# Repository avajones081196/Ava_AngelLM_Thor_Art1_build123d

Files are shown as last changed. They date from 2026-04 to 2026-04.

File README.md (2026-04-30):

# Ava_AngelLM_Thor_Art1_build123d

> **Reconstructing the [AngelLM Thor open-source robot arm](https://github.com/AngelLM/Thor) parts from scratch using [build123d](https://github.com/gumyr/build123d) — with automated STL comparison against the original Fusion 360 exports.**

---

## 🤖 What is This Project?

[Thor](https://github.com/AngelLM/Thor) is a fully open-source, 3D-printable robotic arm designed by AngelLM. This project takes each Thor part and **reconstructs it programmatically** using Python + build123d, driven entirely by coordinate data exported from Fusion 360.

The goal: prove that every part can be rebuilt to **near-perfect geometric accuracy** from first principles — no manual CAD, no guesswork.

---

## ✅ Parts Completed

| # | Part | Volume (mm³) | Vol Error | Sym Diff | Overlap | Bounding Box | Time | Rating |
|---|---|---|---|---|---|---|---|---|
| 1 | `Art1Top_1_Stopper` | 106.87 | 0.008% | 0.009% | 99.999% | ✅ PASS | 1 hr | 🟢 EXCELLENT |
| 2 | `Art1Top_Splitted_A` | 107,906.06 | 0.023% | 0.030% | 99.973% | ✅ PASS | 3.5 hrs | 🟢 EXCELLENT |
| 3 | `Art1Top_Splitted_B` | 45,416.29 | 0.030% | 0.065% | 99.952% | ✅ PASS | 40 min | 🟢 EXCELLENT |
| 4 | `Art2BodyA_Splitted_A` | 102,778.90 | 0.199% | 0.579% | 99.613% | ✅ PASS | 17 hrs | 🟢 EXCELLENT |
| 5 | `Art2BodyA_Splitted_B` | 88,495.39 | 0.058% | 0.283% | 99.887% | ✅ PASS | 10 hrs | 🟢 EXCELLENT |

> **All 5 completed parts: 🟢 EXCELLENT across every metric.**

⏱ **Total time: 32 hrs 10 min**

---

## 📊 Art2BodyA_Splitted_B — Detailed Results

### What the part looks like

A teardrop-shaped body with the hole positioned at the **top** of the teardrop (not at the bulge like Splitted_A) — essentially the geometric counterpart to Splitted_A:

- **Teardrop outer body** (S1): 4 outer arcs (Arc 1 r=75 bottom, Arc 2/Arc 4 r=65 tangents, Arc 3 r=65 top) with a Ø98 mm through-hole at (0, 160). Extruded -32 mm in Z.
- **U-channel pocket** (S2 / G5): irregular crescent + tongue region between Arc 1 of S2 (r=60 inner) and the body's outer boundary, cut 28 mm deep from Z=33 → Z=5, leaving a 5 mm floor.
- **Patterned cluster × 3** (S3, S4 / G6–G10): each instance contains a slot tab (G7), a rectangle-with-hole tab (G8), and a pentagon-shaped through-window cut (G9). Pattern axis: vertical at (0, 160) — centre of the S1 hole.
- **Bounding-box-with-circle feature** (S5 / G11–G13): rect + arc bounding box plus an inner circle, extruded -12.1 mm; circle then cut -12.0 mm leaving a 0.1 mm floor under the hole.
- **Symmetric line-loop cut** (S6 / G14–G15): closed line profile cut ±1.5 mm in Z.
- **Three diameter-bucketed hole sets** (S7 / G16–G19): Ø8.4 / Ø5.9 / Ø3.4 circles cut to depths 2.1 / 3.9 / 8 mm respectively from Z=-1.
- **YZ-plane through-bore** (S8 / G20–G21): single circle cut symmetrically ±50 mm along X.
- **Two YZ-plane prisms** (S9 / G22–G24): two enclosed loops auto-grouped from line endpoints, extrude-joined 30 mm and 26 mm in -X.
- **XY-plane line cutout** (S10 / G25–G26): closed line profile cut 3.5 mm in -Z.
- **YZ-plane mirror** (G27): everything from G22–G26 mirrored across the global YZ plane (S9 prisms re-built at +X with positive extrudes; S10 cutout with X-coords negated).
- **Bottom-face fillets** (G28): 4.99 mm fillet on the three r=65 outer arcs at z=0 (skip Arc 1 r=75). The 4.99 vs 5.0 sidesteps an OCC kernel edge case where exactly r=5 fails on this geometry — 0.01 mm difference is below STL tolerance.

### Guidelines breakdown (G1–G10 + G28; G11–G27 are part of the body construction within the BuildPart context)

| Guideline | Description | CSV |
|---|---|-----|
| G1 | Read S1; circle + 4 arcs at Z=32 → teardrop outline + Ø98 hole | S1 |
| G2 | Extrude outer-arcs-minus-hole region -32 mm in Z | S1 |
| G3 | (Logic stage) export STL/STEP at LAST stage | — |
| G4 | Read S2; identify 3 enclosed sections (hole, U-channel, rim crescent) | S2 |
| G5 | Extrude-cut Sections 2 ∪ 3 by -28 mm; sketch at Z=33 (1 mm overshoot) | S2 |
| G6 | Read S3 + S4; parse 3 sections of S3 + pentagon of S4 | S3, S4 |
| G7 | Extrude-join slot section (Section 3) +8.1 mm in +Z; sketch at Z=4.9 (0.1 mm overshoot into floor) | S3 |
| G8 | Extrude-join rectangle-minus-circle (Section 2) +6 mm at offset Z=7 | S3 |
| G9 | Extrude-cut pentagon (S4) symmetrically ±1.5 mm at Z=10 | S4 |
| G10 | Circular pattern of (G6→G9) × 3 at 0°, 120°, 240° around (0, 160) Z-axis | — |
| G11 | Read S5; bounding-box (lines + arc) + inner circle | S5 |
| G12 | Extrude-join BOTH S5 sections -12.1 mm in -Z | S5 |
| G13 | Extrude-cut S5 inner circle -12.0 mm in -Z (leaves 0.1 mm floor) | S5 |
| G14 | Read S6; closed line loop | S6 |
| G15 | Extrude-cut S6 profile symmetrically ±1.5 mm in Z | S6 |
| G16 | Read S7; bucket circles by Ø8.4 / Ø5.9 / Ø3.4 | S7 |
| G17 | Extrude-cut Ø8.4 circles +2.1 mm in +Z (sketch at Z=-1) | S7 |
| G18 | Extrude-cut Ø5.9 circles +3.9 mm in +Z | S7 |
| G19 | Extrude-cut Ø3.4 circles +8 mm in +Z | S7 |
| G20 | Read S8; circle on YZ plane | S8 |
| G21 | Extrude-cut S8 circle symmetrically ±50 mm in X (through-bore) | S8 |
| G22 | Read S9; auto-group lines into 2 closed loops on YZ plane at X=-9 | S9 |
| G23 | Extrude-join Loop A (Y ∈ [103.7, 108.7]) -30 mm in -X | S9 |
| G24 | Extrude-join Loop B -26 mm in -X | S9 |
| G25 | Read S10; closed line loop on XY plane at Z=8.5 | S10 |
| G26 | Extrude-cut S10 profile -3.5 mm in -Z | S10 |
| G27 | Mirror G22–G26 across global YZ plane (S9 re-built at +X with +X extrudes; S10 X-coords negated) | — |
| G28 | Fillet 3 bottom-face outer arcs (r≈65) at z=0 with r=4.99 mm | — |

### Comparison scorecard

```
███████████████████████████████████████████████████████████
  STL COMPARISON: Build123d  vs  Fusion 360 Original
███████████████████████████████████████████████████████████

  Build123d volume    : 88,495.39 mm³
  Fusion 360 volume   : 88,444.34 mm³
  Absolute difference :     +51.05 mm³  (build123d larger)
  % error             :     0.058%      🟢 EXCELLENT

  Symmetric diff      :    250.53 mm³
  Sym diff %          :     0.283%      🟢 EXCELLENT
  Overlap coverage    :    99.887%      🟢 EXCELLENT

  Bounding box        : ✅ ALL 6 AXES PASS  (max deviation 0.010 mm)

  ─────────────────────────────────────────────────────────
  SUMMARY SCORECARD
  ─────────────────────────────────────────────────────────
  Volume % error          0.058%   🟢 EXCELLENT
  Symmetric diff % error  0.283%   🟢 EXCELLENT
  Overlap coverage       99.89%    ✅
  Bounding box             PASS    ✅
```

### Lessons learned (the 10-hour debug arc)

This part hammered home several Boolean-kernel lessons that build on (and refine) the rules from Splitted_A:

1. **Z-overshoot beats radial offset, every time.** When a cutter or join feature shares a sketch boundary with the host body, the wrong fix is to nudge the radius by 0.01 mm — that creates a sub-tolerance sliver wall that survives `.clean()` but breaks STL tessellation. The right fix is to **extend the cutter perpendicular to the shared face by 1 mm** (e.g. sketch the cutter at Z=33 when the body top is Z=32). The overshoot lives in empty space; the 1 mm margin is 2000× the STL tolerance, well clear of any numerical edge case. Used this for G5 (cut), G7/G13 (join into floor), and the G15 symmetric cut.
2. **For multiple enclosed regions sharing internal dividers, build the union.** S2 had three sections with three "T-junction" divider edges. Drawing each section separately would have made build123d struggle with the shared edges. Instead I traced the **outer perimeter of (Section 2 ∪ Section 3)** as one closed loop — the dividers become interior to the union and vanish. Verified via Euler's formula (V−E+F=2 → exactly 2 bounded faces in the planar graph, confirming "three enclosed sections" reading).
3. **Fillet is the one place where 4.99 vs 5.00 actually matters.** OCC's `fillet()` rejected exactly r=5.0 on the three r=65 bottom arcs (binary search converged: r=4.999... works, r=5.000 fails). Unlike sketch-coincident cases where 0.01 mm offsets create slivers, **fillet is a face-blend operation** — the resulting tangent surface is geometrically clean regardless of the 0.01 mm difference. Visually and dimensionally indistinguishable from r=5.0; OCC just numerically prefers it.
4. **Volume diagnostic libraries don't all agree.** Initial compare report showed a phantom 0.55% volume error because `numpy-stl`'s `get_mass_properties()` integrates signed tetrahedra straight from raw STL triangles — and tessellation of curved fillet surfaces sometimes emits a handful of inverted triangles. trimesh normalizes triangle winding on load and gave the correct value (matching build123d's BREP volume to 4 decimal places). **Use trimesh consistently for all mesh metrics**, not numpy-stl. After fixing the compare script, the real volume error dropped from 0.55% to 0.058% — 10× better.

---

## 📊 Art2BodyA_Splitted_A — Detailed Results

### What the part looks like

The most complex part yet — a stepped teardrop body with a **60-tooth helical gear ring**:

- **Stepped teardrop base**: sections 1+2 (circle + crescent) span Z=0..32; section 3 (bulge) sits on top from Z=5..32
- **Multi-depth pockets** on top face (sections cut to depths -29, -19, -22 mm)
- **4 small bores** (Ø3.4 mm) in bulge floor; central counterbore (Ø10 mm) and through-bore (Ø16.4 mm) clusters
- **Two hexagonal recesses** at Z=11 (circumradius ≈ 3.35 mm)
- **Truncated cone boss** (loft from r=18 @ Z=5 to r=12 @ Z=11), extruded to base
- **Two pentagonal extrusions** on the YZ side face at Y=83 (joined by 6 mm in -Y)
- **60-tooth helical gear ring**: each tooth swept along Z=13→Z=3 with 5.97° twist, patterned around global Z-axis (radial range r=57.5 → 62.92 mm)

### Guidelines breakdown (31 guidelines, G1–G31)

| Guideline | Description | CSV |
|---|---|-----|
| G1 | Read S1; sketch circle + 4 arcs at Z=32 → 3 enclosed sections | S1 |
| G2 + G4 | **Stepped teardrop via cut-first**: full silhouette extrude Z=32→0, then Boolean cut for bulge below Z=5 | S1 |
| G3 | (Logic stage) Base complete | — |
| G5 | Fillet bottom-face arcs r=5 mm (skip Arc 2 r=75) | — |
| G6–G9 | S2 cuts on top face (circle / crescent / bulge: -29 / -19 / -22 mm) | S2 |
| G10–G11 | 4 small bores in bulge floor (-6 mm) | S3 |
| G12–G13 | S4 single circle from bottom face (+1.1 mm) | S4 |
| G14–G16 | S5 loft + extrude-join (truncated cone) | S5 |
| G17–G18 | S6 holes & slot cluster on bottom face | S6 |
| G19–G21 | S7 three sections, two depths (4 mm and 9 mm) | S7 |
| G22–G23 | S8 two hexagon recesses at Z=11 | S8 |
| G24–G25 | S9 two pentagon extrude-joins on YZ plane | S9 |
| G26–G27 | S10 ring extrude-join (Z=13 → Z=2.7) | S10 |
| G28–G29 | S11 tooth profile + S12 sweep path | S11, S12 |
| G30 | Helical tooth via 21-slice rotated loft (twist +5.97°) | — |
| G31 | Circular pattern × 60 around global Z-axis | — |

### Comparison scorecard

```
███████████████████████████████████████████████████████████
  STL COMPARISON: Build123d  vs  Fusion 360 Original
███████████████████████████████████████████████████████████

  Build123d volume    : 102,778.90 mm³
  Fusion 360 volume   : 102,979.85 mm³
  Absolute difference :    -204.77 mm³
  % error             :     0.199%      🟢 EXCELLENT

  Symmetric diff      :     596.42 mm³
  Sym diff %          :     0.579%      🟢 EXCELLENT
  Overlap coverage    :    99.613%      🟢 EXCELLENT

  Bounding box        : ✅ ALL 6 AXES PASS  (max deviation 0.010 mm)

  ─────────────────────────────────────────────────────────
  SUMMARY SCORECARD
  ─────────────────────────────────────────────────────────
  Volume % error          0.199%   🟢 EXCELLENT
  Symmetric diff % error  0.579%   🟢 EXCELLENT
  Overlap coverage       99.61%    🟢 EXCELLENT
  Bounding box             PASS    ✅
```

### Lessons learned (the 17-hour debug arc)

This part exposed several Boolean-kernel pitfalls that the simpler Art1 parts didn't hit. The key fixes — written up as universal rules in [`build123d_short_prompts.md`](./build123d_short_prompts.md) — are:

1. **Never share a sketch curve between two extrudes that get fused.** G2 + G4 originally extruded sections 1+2 and all-3-sections separately, both containing Arc 2 in their sketches. The fuse left Arc 2 as an internal seam → 14 open edges. **Fix**: build the full outer silhouette in one extrude, then Boolean-cut the bulge below Z=5.
2. **Avoid coincident faces between cutter and host.** First cut attempt produced 1483 open edges because the cutter's side walls (Arcs 3, 4, 1) sat exactly coincident with the host's outer walls. **Fix**: replace those arcs with a generous bounding rectangle that lies entirely outside the host. Boolean only acts where they overlap, so the rectangle's overhang is geometrically free.
3. **Z-inset for swept teeth.** Tooth path of exact Z=13→Z=3 produced 9 open edges where tooth end-faces coincided with the ring's top/bottom faces. **Fix**: shrink path 0.05 mm at each end (Z=12.95 → Z=3.05). Each tooth ends 0.05 mm *inside* the ring at top and bottom — invisible because the ring's flat top/bottom faces project over those gaps, and the Boolean fuse is now isolated from coincident-face conflicts.
4. **Three-gate STL validator before export.** trimesh's `is_watertight=True` does NOT guarantee Fusion will accept the STL — Fusion also checks face-orientation consistency and positive signed volume. **Fix**: always run `trimesh.repair.fix_winding()` + `fix_normals()` before export, then gate on three checks: watertight + positive volume + volume matches BREP within 1%.

---

## 📊 Art1Top_Splitted_B — Detailed Results

### What the part looks like

A stepped annular ring with three concentric circles defining two regions:

- **Inner ring** (r25→r35): extends both upward (+7 mm) and downward (-6 mm) from the sketch plane
- **Outer flange** (r25→r47): extends upward (+7 mm) only
- **6 bolt holes** (r≈1.7 mm) on a 30 mm bolt circle, evenly spaced

### Guidelines breakdown (6 guidelines, G1–G6)

| Guideline | Description | CSV |
|---|---|-----|
| G1 | Read 3 concentric circles (inner r=25, middle r=35, outer r=47) | S1 |
| G2 | Extrude inner-to-middle -6 mm (-Z) and +7 mm (+Z); inner-to-outer +7 mm (+Z) join | S1 |
| G3 | (Logic stage) Ring complete | — |
| G4 | Read bolt hole circle (r≈1.7 mm at radius 30 mm) | S2 |
| G5 | Extrude-cut hole 15 mm through-all | S2 |
| G6 | Circular pattern × 6 around global Z axis | — |

### Comparison scorecard

```
███████████████████████████████████████████████████████████
  STL COMPARISON: Build123d  vs  Fusion 360 Original
███████████████████████████████████████████████████████████

  Build123d volume    : 45,416.29 mm³
  Fusion 360 volume   : 45,429.81 mm³
  Absolute difference :    −13.52 mm³
  % error             :     0.030%      🟢 EXCELLENT

  Symmetric diff      :     29.74 mm³
  Sym diff %          :     0.065%      🟢 EXCELLENT
  Overlap coverage    :    99.952%      🟢 EXCELLENT

  Bounding box        : ✅ ALL 6 AXES PASS  (max deviation 0.015 mm)

  ─────────────────────────────────────────────────────────
  SUMMARY SCORECARD
  ─────────────────────────────────────────────────────────
  Volume % error          0.030%   🟢 EXCELLENT
  Symmetric diff % error  0.065%   🟢 EXCELLENT
  Overlap coverage       99.95%    🟢 EXCELLENT
  Bounding box             PASS    ✅
```

---

## 📊 Art1Top_Splitted_A — Detailed Results

### What the part looks like

A large annular disc (inner radius 25 mm, outer radius 75 mm) with multiple features:

- **6 countersink holes** on a 30 mm bolt circle (counterbore + through-bore)
- **4 rectangular bosses** with side holes, pentagon slots, and wedge extrusions (mirrored in 4 quadrants)
- **Tilted hex + circle cuts** on 45° angled faces
- **Curved cutout profiles** at wedge bases
- **Bottom-face pocket** (circle cut from Z=0)

### Guidelines breakdown (20 guidelines, G1–G20)

| Guideline | Description | CSV |
|---|---|-----|
| G1–G3 | Annular ring (inner/outer circles, extrude −5 mm) | S1 |
| G4–G6 | Countersink holes × 6 (counterbore +3, through-bore −2, circular pattern) | S2 |
| G7–G8 | Rectangular boss (10×23 mm, extrude +15 mm) | S3 |
| G9–G10 | Side hole through rectangular boss | S4 |
| G11–G12_1 | Wedge profile extrusions (triangle +13, polygon +5) | S5 |
| G12_2–G12_3 | Curved cutout at wedge base (+30 mm cut) | S9 |
| G13–G14 | Hexagon + circle cut on 45° tilted plane | S6 |
| G15–G16 | Pentagon slot cut (±1.5 mm symmetric) | S7 |
| G17 | Mirror G7–G16 across YZ plane (X → −X) | — |
| G18 | Mirror G7–G17 across XZ plane (Y → −Y) | — |
| G19–G20 | Bottom-face circle pocket (r=5 mm, 2 mm deep) | S8 |

### Comparison scorecard

```
  Build123d volume    : 107,906.06 mm³
  Fusion 360 volume   : 107,931.29 mm³
  % error             :     0.023%      🟢 EXCELLENT

  Symmetric diff %    :     0.030%      🟢 EXCELLENT
  Overlap coverage    :    99.973%      🟢 EXCELLENT
  Bounding box        : ✅ ALL 6 AXES PASS
```

---

## 📊 Art1Top_1_Stopper — Detailed Results

### What the part looks like

A circular disc (radius ≈ 4.4 mm) with a raised central strip — two parallel chord lines inside the circle divide it into three regions:

```
        ╭─────────────────╮
        │   Region B (arc)│   ← flat
        ├─────────────────┤   ← chord at Y = +1.5
        │   Region A      │   ← raised +1.0 mm (the "stopper" ridge)
        ├─────────────────┤   ← chord at Y = -1.5
        │   Region C (arc)│   ← flat
        ╰─────────────────╯
```

### Comparison scorecard

```
  Build123d volume    : 106.87 mm³
  Fusion 360 volume   : 106.86 mm³
  % error             :   0.008%       🟢 EXCELLENT

  Symmetric diff %    :   0.009%       🟢 EXCELLENT
  Overlap coverage    :  99.999%       🟢 EXCELLENT
  Bounding box        : ✅ ALL 6 AXES PASS
```

---

## 🗂️ Project Structure

Each part lives in its own folder under `20260422_assign/`:

```
20260422_assign/
├── Art1Top_1_Stopper/
│   ├── csv_data_Art1Top_1_Stopper/
│   ├── csv_merged/
│   ├── 0_preprocess_csvs.py
│   ├── Art1Top_1_Stopper_build123d.py
│   ├── Art1Top_1_Stopper_compare_stl_files.py
│   ├── Art1Top_1_Stopper_G_1_3.stl
│   ├── Art1Top_1_Stopper_G_1_3.step
│   └── Art1Top_1_Stopper_original.stl
│
├── Art1Top_Splitted_A/
│   ├── csv_data_Art1Top_Splitted_A/
│   ├── csv_merged/                        ← S1–S9 cleaned CSVs
│   ├── 0_preprocess_csvs.py
│   ├── Art1Top_Splitted_A_build123d.py    ← 20 guidelines (G1–G20)
│   ├── Art1Top_Splitted_A_compare_stl_files.py
│   ├── Art1Top_Splitted_A_G_1_20.stl
│   ├── Art1Top_Splitted_A_G_1_20.step
│   └── Art1Top_Splitted_A_original.stl
│
├── Art1Top_Splitted_B/
│   ├── csv_data_Art1Top_Splitted_B/
│   ├── csv_merged/                        ← S1–S2 cleaned CSVs
│   ├── 0_preprocess_csvs.py
│   ├── Art1Top_Splitted_B_build123d.py    ← 6 guidelines (G1–G6)
│   ├── Art1Top_Splitted_B_compare_stl_files.py
│   ├── Art1Top_Splitted_B_G_1_6.stl
│   ├── Art1Top_Splitted_B_G_1_6.step
│   └── Art1Top_Splitted_B_original.stl
│
├── Art2BodyA_Splitted_A/
│   ├── csv_data_Art2BodyA_Splitted_A/
│   ├── csv_merged/                        ← S1–S12 cleaned CSVs
│   ├── 0_preprocess_csvs.py
│   ├── Art2BodyA_Splitted_A_build123d.py  ← 31 guidelines (G1–G31)
│   ├── Art2BodyA_Splitted_A_compare_stl_files.py
│   ├── Art2BodyA_Splitted_A_G_1_31.stl
│   ├── Art2BodyA_Splitted_A_G_1_31.step
│   └── Art2BodyA_Splitted_A_original.stl
│
└── Art2BodyA_Splitted_B/
    ├── csv_data_Art2BodyA_Splitted_B/
    ├── csv_merged/                        ← S1–S10 cleaned CSVs
    ├── 0_preprocess_csvs.py
    ├── Art2BodyA_Splitted_B_build123d.py  ← G1–G10 + G28 (G11–G27 in body construction)
    ├── Art2BodyA_Splitted_B_compare_stl_files.py
    ├── Art2BodyA_Splitted_B_G_1_28.stl
    ├── Art2BodyA_Splitted_B_G_1_28.step
    └── Art2BodyA_Splitted_B_original.stl
```

---

## 🔧 How It Works

### The Pipeline (3 scripts per part)

```
Raw Fusion CSVs
      ↓
[0_preprocess_csvs.py]     → cleans duplicates, merges split files → csv_merged/
      ↓
[PartName_build123d.py]    → reads CSVs, builds 3D geometry, exports STL + STEP
      ↓
[PartName_compare_stl_files.py]  → compares built STL vs Fusion original
```

---

### Script 1 — `0_preprocess_csvs.py`

Reads raw Fusion 360 coordinate CSVs and produces clean, deduplicated versions:

- Handles split files (e.g. `S25_1.csv + S25_2.csv → S25.csv`)
- Removes geometry-aware duplicates:
  - Lines: `A→B == B→A` (direction-invariant)
  - Triangles: `A,B,C == B,C,A` (rotation-invariant)
  - Points: exact match
- Renumbers `Steps` column sequentially
- **Incremental** — skips shapes already in `csv_merged/` (safe to re-run)

---

### Script 2 — `PartName_build123d.py`

Rebuilds the part using [build123d](https://github.com/gumyr/build123d). Each script follows a numbered guideline system:

| Guideline | Always means |
|---|---|
| **G1** | Read CSV(s), extract geometry (circles, lines, polygons) |
| **G2–Gn** | Perform extrusions, cuts, sweeps, patterns, mirrors etc. |
| **Last G** | Always last — `clean()` → watertight check → export STL + STEP → write summary |

**File naming convention:**
```
PartName_G_1_N.stl          ← STL output  (N = last guideline number)
PartName_G_1_N.step         ← STEP output
PartName_summary_G_1_N.txt  ← Build log
```

**Pre-export validator (since Art2BodyA_Splitted_A)** — replaces the simple watertight check, gates on three conditions:

```python
trimesh.repair.fix_winding(mesh)   # consistent CCW winding
trimesh.repair.fix_normals(mesh)   # outward-pointing normals

wt      = mesh.is_watertight
pos_vol = mesh.volume > 0
vol_ok  = abs(mesh.volume - brep_vol) / abs(brep_vol) < 0.01

if wt and pos_vol and vol_ok:
    mesh.export(STL_PATH)          # ship validated mesh
```

This eliminates the *"mesh not oriented / not positive volume"* error Fusion would intermittently throw on import — Fusion checks face orientation in addition to manifoldness, and `is_watertight=True` alone doesn't guarantee that.

---

### Script 3 — `PartName_compare_stl_files.py`

Compares the built STL against the original Fusion 360 STL across four metrics:

| Metric | What it measures |
|---|---|
| **Volume % error** | How close the total volume is |
| **Symmetric difference** | Spatial overlap quality — how well the shapes align in 3D space |
| **Overlap coverage** | What % of the original is covered by the reconstruction |
| **Bounding box** | Whether all 6 axis extents match within ±0.1 mm |

Ratings: 🟢 EXCELLENT / 🟡 GOOD / 🟠 ACCEPTABLE / 🔴 POOR

> **⚠ Important — use `trimesh` consistently for volume.** Earlier versions of the compare script used `numpy-stl`'s `get_mass_properties()` for the headline volume reading and `trimesh` for the symmetric-difference section, which gave **two different volumes for the same file** on meshes with many curved fillet faces (Splitted_B initially showed a phantom 0.55% error this way). Cause: numpy-stl integrates signed tetrahedra straight from raw STL triangles, while trimesh normalizes triangle winding on load. Fix: replace the `from stl import mesh` reading with `trimesh.load(file).volume` everywhere — apples-to-apples comparison.

---

## 🛠️ Environment Setup

### Requirements

- Python 3.11
- macOS (tested on MacBook Air, Apple Silicon)
- VS Code + [OCP CAD Viewer extension](https://github.com/bernhard-42/vscode-ocp-cad-viewer)

### Create the master environment

```bash
python3.11 -m venv ~/Documents/ava_build123d/build123d_master_env
source ~/Documents/ava_build123d/build123d_master_env/bin/activate
pip install --upgrade pip
pip install build123d==0.7.0 ocp_vscode==3.3.4 numpy-stl trimesh manifold3d rtree networkx
```

> `networkx` is optional — used by trimesh for boundary-loop stitching during mesh repair. Recommended.

### Add a handy shell alias (optional but recommended)

```bash
echo 'alias buildenv="source ~/Documents/ava_build123d/build123d_master_env/bin/activate"' >> ~/.zshrc
source ~/.zshrc
```

Now you can just type `buildenv` to activate.

---

## 🚀 Running a Part (Master Startup Checklist)

### 🔧 One-Time Per Project Folder

1. **Open project folder** in VS Code: `File` → `Open Folder`
2. **Lock the interpreter:**
   ```bash
   mkdir -p .vscode && cat > .vscode/settings.json << 'EOF'
   {
       "python.defaultInterpreterPath": "/Users/avajones/Documents/ava_build123d/build123d_master_env/bin/python"
   }
   EOF
   ```

### ▶️ Every Session

3. **Open OCP viewer:** `Cmd+Shift+P` → `OCP CAD Viewer: Open Viewer`
   - If interpreter prompt appears → click `yes` → pick `build123d_master_env`
4. **Check port:** read bottom-right corner `OCP: XXXX` — match in script's `set_port(XXXX)`
5. **Tab 2 — run scripts:**
   ```bash
   buildenv
   cd ~/Documents/ava_build123d/20260422_assign/PartName
   python 0_preprocess_csvs.py
   python PartName_build123d.py
   python PartName_compare_stl_files.py
   ```

> **Port note:** The OCP viewer port varies per session. Always check `OCP: XXXX` in the bottom-right corner of VS Code and match `set_port()` accordingly.

---

## 🐛 Known Gotchas

| Issue | Cause | Fix |
|---|---|-----|
| `Connection refused Errno 61` | OCP server not running | Open OCP viewer panel before running script |
| Geometry not showing | Script port ≠ viewer port | Match `set_port()` to bottom-right `OCP: XXXX` |
| Script runs old version | Unsaved file (● dot on tab) | `Cmd+S` — confirm dot disappears |
| `No module named ocp_vscode` | VS Code using wrong Python | Run `.vscode/settings.json` fix once per folder |
| `Location()` on `Plane.YZ` misplaced | `Location` uses **global** coords, not local | Use `Location((0, Y, Z))` not `Location((Y, Z, 0))` |
| Thin surface artifact on cuts | Sketch plane sits exactly on body face | Use `both=True` to cut in both directions |
| `Location` context manager error | `with Location(...)` not supported | Use `Plane.move(Location(...))` instead |
| `open_edges = 14` after fuse | Two extrudes share a sketch curve → internal seam | Single outer-silhouette extrude + Boolean cut |
| `open_edges` = 1000+ after cut | Cutter side walls coincident with host walls | Replace cutter outline with bounding rectangle outside host |
| Fusion: *"mesh not oriented"* on import | trimesh `is_watertight` doesn't check face orientation | Always run `fix_winding` + `fix_normals` before export |
| Script hangs mid-run | Intermediate `show()` blocking | Comment out all but final `show()` |
| Sliver wall after sketch-coincident cut | Tried 0.01 mm radial offset to avoid coincidence | Use Z-overshoot instead — extend cutter ≥1 mm in extrude direction |
| `fillet(r=5.0)` rejected on tangent arcs | OCC kernel numerical edge case at exact radius | Use 4.99 — face-blend op, 0.01 mm difference is below STL tolerance |
| Compare script reports 0.5% phantom volume error | numpy-stl + trimesh disagree on filleted meshes | Use `trimesh.load(f).volume` consistently in compare script |

---

## 📦 Dependencies

```
build123d==0.7.0
ocp_vscode==3.3.4
numpy-stl
trimesh
manifold3d
rtree
networkx          # optional — trimesh boundary-loop stitching
```

---

## 🗺️ Roadmap

- [x] `Art1Top_1_Stopper` — 🟢 EXCELLENT (0.008% vol error) — 1 hr
- [x] `Art1Top_Splitted_A` — 🟢 EXCELLENT (0.023% vol error) — 3.5 hrs
- [x] `Art1Top_Splitted_B` — 🟢 EXCELLENT (0.030% vol error) — 40 min
- [x] `Art2BodyA_Splitted_A` — 🟢 EXCELLENT (0.199% vol error) — 17 hrs
- [x] `Art2BodyA_Splitted_B` — 🟢 EXCELLENT (0.058% vol error) — 10 hrs

---

## 📄 License

This reconstruction project is open source. The original Thor design files belong to [AngelLM](https://github.com/AngelLM/Thor) under their respective license.

---

## 🙏 Credits

- **[AngelLM](https://github.com/AngelLM)** — original Thor robot arm design
- **[build123d](https://github.com/gumyr/build123d)** — the Python CAD library powering all reconstructions
- **[OCP CAD Viewer](https://github.com/bernhard-42/vscode-ocp-cad-viewer)** — VS Code 3D preview
- **[trimesh](https://trimesh.org/)** + **[manifold3d](https://github.com/elalish/manifold)** — STL comparison engine

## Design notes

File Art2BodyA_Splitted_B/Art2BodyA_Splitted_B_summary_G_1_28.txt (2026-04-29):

============================================================
Summary  :  Art2BodyA_Splitted_B_summary_G_1_28
Guidelines covered: G1 to G28
============================================================

-- G1 : Profile (S1, Z=32) --
  Inner Circle (hole) : centre=(0.000, 160.000)  r=49.000
  Arc 1 (bottom)      : centre=(0.000, -0.001)  r=75.001
  Arc 2 (right tang.) : centre=(102.470, 80.000)  r=65.000
  Arc 3 (top conn.)   : centre=(0.000, 160.000)  r=65.000
  Arc 4 (left tang.)  : centre=(-102.470, 80.000)  r=65.000
  Sketch plane Z = 32.0

-- G2 : Extrude region (outer arcs minus circle hole) --
  Depth: -32.0 mm in -Z  (Z=32.0 -> Z=0)

-- G4 : Profile (S2, Z=33) — three enclosed sections --
  Section 1 (HOLE, NOT cut): circle r=49.000 at (0.000, 160.000)  dia=98.000
  Section 2 (upper U-channel)
  Section 3 (rim crescent)

-- G5 : Extrude-cut Sections 2 ∪ 3 (NOT Section 1) --
  Sketch Z = 33.0  (1 mm above body top Z=32 — Z-overshoot)
  Cut depth: 28.0 mm in -Z   (Z=33.0 → Z=5.0)
  Result: 5 mm floor at Z=0..5; pocket reaches body sidewalls

-- G6 : Profile (S3, Z=4.9) — three enclosed sections --
  Section 1 : circle r=1.700 at (0.000, 205.000)
  Section 2 : rectangle (-5,201)→(5,209) MINUS Section-1 circle
  Section 3 : slot lines+arc (top arc r=64.863 c=(-0.000, 155.621))
  Sketch plane Z = 4.9  (0.1 mm BELOW floor top Z=5 — Z-overshoot)

-- G7 : Extrude-join Section 3 (slot) --
  Depth: +8.1 mm in +Z  (Z=4.9 → Z=13.0)

-- G8 : Extrude-join Section 2 (rect - circle) --
  Offset: +2.1 mm above sketch plane → start Z=7.0
  Depth:  +6.0 mm in +Z  (Z=7.0 → Z=13.0)
  Circle hole carries through Section-2 tab (Z=7.0..13.0)

-- G9 : Profile (S4, Z=10) + symmetric extrude-cut --
  S4 profile: pentagon-like outline (7 lines, closed)
  Sketch plane Z = 10.0
  Cut: ±1.5 mm symmetric in Z  (Z=8.5 → Z=11.5, total 3.0 mm)
  Implementation: TWO subtract extrudes from sketch (+1.5 and -1.5)

-- G10 : Circular pattern of (G6 → G9) --
  Pattern axis: vertical at (0.0, 160.0) (centre of S1 circle)
  Quantity: 3 instances at 0.0°, 120.0°, 240.0°
  G7+G8 join, G9 cut applied at each rotated position

-- G11 : Profile (S5, Z=25.0) — bounding box (lines+arc) + inner circle --
  Inner circle: centre=(0.000, 215.000)  r=1.700
  Bounding box: rectangle x=[-5, 5], y=[210, 219.791] + small step to y=220.391 + top arc

-- G12 : Extrude-join BOTH S5 sections (box + circle) --
  Depth: -12.1 mm in -Z  (Z=25.0 → Z=12.9)

-- G13 : Extrude-cut S5 inner circle --
  Depth: -12.0 mm in -Z  (Z=25.0 → Z=13.0)
  Leaves 0.1 mm of material under the hole at the bottom of the G12 prism

-- G14 : Profile (S6, Z=20.5) — closed loop of lines --
  S6 profile: 7 lines forming a single closed loop

-- G15 : Extrude-cut S6 profile symmetrically --
  Cut: ±1.5 mm symmetric in Z  (Z=19.0 → Z=22.0, total 3.0 mm)
  Implementation: TWO subtract extrudes from sketch (+1.5 and -1.5)

-- G16 : Profile (S7, Z=-1.0) — circles bucketed by diameter --
  Circles dia ≈ 8.4: 2 found
  Circles dia ≈ 5.9: 4 found
  Circles dia ≈ 3.4: 4 found

-- G17 : Extrude-cut dia ≈ 8.4 circles --
  Depth: +2.1 mm in +Z  (Z=-1.0 → Z=1.1)
  Produces 1.1 mm-deep counterbore-style holes through floor at Z=0

-- G18 : Extrude-cut dia ≈ 5.9 circles --
  Depth: +3.9 mm in +Z  (Z=-1.0 → Z=2.9)

-- G19 : Extrude-cut dia ≈ 3.4 circles --
  Depth: +8.0 mm in +Z  (Z=-1.0 → Z=7.0)

-- G20 : Profile (S8, YZ-plane at X=0.0) — circle --
  Circle: centre_Y=99.850, centre_Z=8.000  r=1.700

-- G21 : Extrude-cut S8 circle symmetrically along X --
  Cut: ±50 mm symmetric in X  (through-bore along X)
  Implementation: TWO subtract extrudes from YZ sketch (+50 and -50)

-- G22 : Profile (S9, YZ-plane at X=-9.0) — TWO closed loops --
  Auto-grouped into 2 loops by walking endpoints
  Loop A (Y range 103.7→108.7): 6 lines
  Loop B (other):                6 lines

-- G23 : Extrude-join Loop A by 30 mm in -X --
  Sketch at X=-9.0 → solid extends toward X=-39.0

-- G24 : Extrude-join Loop B by 26 mm in -X --
  Sketch at X=-9.0 → solid extends toward X=-35.0

-- G25 : Profile (S10, Z=8.5) — single enclosed region --
  S10 profile: 7 lines forming a single closed loop

-- G26 : Extrude-cut S10 profile by 3.5 mm in -Z --
  Cut: Z=8.5 → Z=5.0

-- G27 : Mirror G22-G26 across the global YZ plane --
  S9 features re-built at X=9.0 (mirror of -9.0)
    Loop A extruded +30 mm in +X
    Loop B extruded +26 mm in +X
  S10 feature: every X coordinate negated, then cut -3.5 mm in -Z

-- G28 : Fillet 3 bottom-face outer arcs (r≈65) at z=0 --
  Selection: bottom face via faces().sort_by(Axis.Z)[0], filter edges by radius ≈65
  Fillet radius applied: 4.99 (literal 5.0 fails OCC kernel; 0.01 mm difference
    is below STL tolerance, visually identical)
  Skipped Arc 1 (r=75 bottom of teardrop)

-- G3 : Export --
  STL  : Art2BodyA_Splitted_B_G_1_28.stl
  STEP : Art2BodyA_Splitted_B_G_1_28.step

Watertight check  : True
Open edges        : 0
STL volume        : 88495.38916429707 mm^3
build123d volume  : 88495.45758018733 mm^3
============================================================

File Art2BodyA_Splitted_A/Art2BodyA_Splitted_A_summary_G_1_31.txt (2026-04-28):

============================================================
Summary  :  Art2BodyA_Splitted_A_summary_G_1_31
Guidelines covered: G1–G31
============================================================

── G1 : Profile (S1) ──
  Circle      : r=65.000 mm at origin
  Arc 2 (conc): r=75.001 mm
  Arcs 1,3    : r=65.000 mm  (tangent arcs)
  Arc 4 (top) : r=75.001 mm
  Sketch plane Z = 5.0

── G2 : Extrude sections 1+2 ──
  Depth: -5.0 mm (-Z)

── G4 : Extrude all sections ──
  Depth: +27.0 mm (+Z) join

── G5 : Fillet ──
  Radius: 5.0 mm on bottom-face arcs 1,3,4 (Arc2 r=75 skipped)

── G6 : Profile (S2, Z=32) ──
  Circle r=62.5 at origin
  Arc 1 (conc): r=65.000 mm
  Arc 2 (left tangent)  : from (-40.353, 47.727) → (-34.21, 95.512)
  Arc 3 (top connecting): from (-34.21, 95.512) → (34.21, 95.512)
  Arc 4 (right tangent) : from (34.21, 95.512) → (40.353, 47.727)

── G7 : Cut circle section ──
  -Z depth: 29.0 mm   +Z depth: 1.0 mm

── G8 : Cut adjacent crescent ──
  -Z depth: 19.0 mm   +Z depth: 1.0 mm

── G9 : Cut third/bulge section ──
  -Z depth: 22.0 mm   +Z depth: 1.0 mm

── G10 : Profile (S3) ──
  4 circle(s):
  3_point_circle_1           centre=(-28.5001, 73.5000)  r=1.6999  Z=10.0
  3_point_circle_2           centre=(-28.5001, 86.5000)  r=1.6999  Z=10.0
  3_point_circle_3           centre=(28.4999, 86.5000)  r=1.6999  Z=10.0
  3_point_circle_4           centre=(28.4999, 73.5000)  r=1.6999  Z=10.0

── G11 : Cut all S3 circles ──
  Sketch Z=10.0 (bulge floor)  -Z depth: 6.0 mm  → holes reach Z=4.0

── G12 : Profile (S4) ──
  1 circle(s):
  3_point_circle_1           centre=(0.0002, -54.5000)  r=4.1998  Z=0.0

── G13 : Cut S4 circle ──
  Sketch Z=0.0 (bottom face)  +Z depth: 1.1 mm  → cut reaches Z=1.1

── G14 : Profile (S5) ──
  2 circle(s):
  3_point_circle_2           centre=(0.0003, 0.0000)  r=17.9997  Z=5.0
  3_point_circle_1           centre=(0.0002, 0.0000)  r=11.9998  Z=11.0

── G15 : Loft between S5 circles ──
  r=17.9997 @ Z=5.0  →  r=11.9998 @ Z=11.0

── G16 : Extrude-join larger circle to base ──
  r=17.9997  Z=5.0 → Z=0  (depth: 5.0 mm -Z)  then union with base body

── G17 : Profile (S6, Z=0) ──
  Lines : 6
  3_point_circle_1           centre=(11.0001,0.0000)  r=1.6999  d=3.3997
  3_point_circle_2           centre=(-10.9999,0.0000)  r=1.6999  d=3.3997
  3_point_circle_3           centre=(0.0001,0.0000)  r=4.9999  d=9.9999
  3_point_circle_4           centre=(0.0002,0.0000)  r=8.1998  d=16.3995

── G18 : Cut d≈3.4 (×2) and d≈10 circles ──
  +Z depth: 12.0 mm   -Z depth: 0.5 mm

── G19 : Profile (S7, Z=0) — three enclosed sections ──
  6 Lines + 4 Arcs (r≈8.2008)
  Section A (LEFT):   Lines 1-3 + Arc4 → rectangle closed by arc
    corners: (-15.3,-3.5) (-15.3,3.5) (-7.416,3.5) arc4 (-7.416,-3.5)
  Section B (RIGHT):  Lines 4-6 + Arc2 → rectangle closed by arc
    corners: (7.416,3.5) (15.3,3.5) (15.3,-3.5) (7.416,-3.5) arc2
  Section C (CENTER): Arcs 1+2+3+4 → enclosed circle r≈8.2008

── G20 : Extrude-cut ALL three S7 sections ──
  Sections A, B, C each cut +4.0 mm in +Z  (sketch at Z=0.0)

── G21 : Extrude-cut center arc section only ──
  Section C only, total 9.0 mm in +Z  (sketch at Z=0.0, cut Z=0 → Z=9)
  Sections A & B remain at 4 mm depth; Section C reaches 9 mm depth

── G22 : Profile (S8, Z=11) — two hexagons ──
  21 lines total → 2 enclosed hexagon regions
  RIGHT hexagon: centre=(11.000, -0.000)  circumradius=3.3498  Z=11.0
  LEFT  hexagon: centre=(-11.000,  -0.000)  circumradius=3.3498  Z=11.0

── G23 : Extrude-cut both hexagons ──
  -Z depth: 4.0 mm  (Z=11.0 → Z=7.0)
  +Z depth: 0.2 mm  (Z=11.0 → Z=11.2)

── G24 : Profile (S9, Y=83) — two pentagon regions ──
  RIGHT region: 5-vertex polygon  X>0  at Y=83.0
    vertices (X,Z): [(25.0, 27.0), (32.534, 27.0), (33.534, 27.0), (33.534, 18.466), (32.534, 19.466)]
  LEFT  region: 5-vertex polygon  X<0  at Y=83.0
    vertices (X,Z): [(-25.0, 27.0), (-32.534, 27.0), (-33.534, 27.0), (-33.534, 18.466), (-32.534, 19.466)]

── G25 : Extrude-join both S9 pentagons ──
  Both regions extruded +6.0 mm in -Y  (Y=83.0 → Y=77.0)

── G26 : Profile (S10) — two circles ──
  2 circles
  3_point_circle_2           centre=(-0.0002,0.0000)  r=63.5002  Z=13.0
  3_point_circle_1           centre=(-0.0002,0.0000)  r=62.0002  Z=13.0

── G27 : Extrude-join region between S10 circles ──
  Extruded ring depth: 10.3 mm in -Z

── G28 : Profile (S11) — enclosed tooth profile ──
  18 edges (Lines/Arcs) combined into a Face at Z=13.0

── G29 : Profile (S12) — sweep path ──
  Line generated along Z axis from Z=12.95 to Z=3.05

── G30 : Helical tooth sweep ──
  Swept S11 tooth profile along S12 path with a twist angle of 5.97 degrees.

── G31 : Circular Pattern ──
  Patterned the G30 swept tooth profile 60 times around the global Z-axis.

Watertight check  : True
STL volume        : 102778.90190674244 mm³
build123d volume  : 102787.96923762176 mm³

Exported files:
  STL  : Art2BodyA_Splitted_A_G_1_31.stl
  STEP : Art2BodyA_Splitted_A_G_1_31.step
============================================================

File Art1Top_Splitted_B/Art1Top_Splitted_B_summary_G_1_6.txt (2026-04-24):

============================================================
Summary  :  Art1Top_Splitted_B_summary_G_1_6
Guidelines covered: G1–G6
============================================================

── G1-G2 : Annular ring (S1, 3 circles) ──
  Inner radius    : 25.0002 mm
  Middle radius   : 35.0001 mm
  Outer radius    : 46.9999 mm
  Sketch plane Z  : 6.0000 mm
  Inner-to-middle : -6.0 mm (-Z), +7.0 mm (+Z)
  Inner-to-outer  : +7.0 mm (+Z) join

── G4-G6 : Bolt holes × 6 (S2) ──
  Hole radius      : 1.6999 mm
  Bolt-circle r    : 30.0001 mm
  Hole depth       : 15.0 mm (both directions)
  Hole count       : 6
  Start angle      : 0.0°

Watertight check  : True
STL volume        : 45416.24644972925 mm³
build123d volume  : 45435.074775887144 mm³

Exported files:
  STL  : Art1Top_Splitted_B_G_1_6.stl
  STEP : Art1Top_Splitted_B_G_1_6.step
============================================================

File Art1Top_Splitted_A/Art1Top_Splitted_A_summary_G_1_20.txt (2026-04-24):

============================================================
Summary  :  Art1Top_Splitted_A_summary_G_1_20
Guidelines covered: G1–G20
============================================================

── G1-G2 : Annular ring (S1) ──
  S1 inner radius   : 25.0002 mm
  S1 outer radius   : 75.0001 mm
  Extrusion         : 5.0 mm  (−Z)

── G4-G6 : Countersink holes × 6 (S2) ──
  Counterbore r=2.9501 cut +3.0 (+Z)
  Through-bore r=1.6999 cut -2.0 (−Z)
  Bolt-circle r=30.0000  count=6

── G7-G8 : Rectangular boss (S3) ──
  Centre (50.0, -31.5)  10.0×23.0 mm  +15.0 mm (+Z)

── G9-G10 : Side hole (S4) ──
  YZ plane X=55.0  r=1.6999  through-all

── G11-G12 : Profile extrusions (S5) ──
  G12_1: YZ plane X=17.0
    Section 1 (triangle):  +13.0 mm in +X
    Section 2 (polygon):   +5.0 mm in +X
  G12_2: S9 cutout on XY plane Z=5.0
    Profile: 8 vertices
  G12_3: Extrude cut +30.0 mm in +Z

── G13-G14 : Hex + circle cut on tilted plane (S6) ──
  Tilted plane Y+Z=-23 (45°)
  Circle r=1.7000  cut through-all
  Hexagon cut: -2.0 mm offset, -8.0 mm depth

── G15-G16 : Pentagon slot cut (S7) ──
  YZ plane X=50.0
  Pentagon (house shape): 5 vertices
  Symmetric cut: ±1.5 mm in X (total 3.0 mm)

── G17 : Mirror across YZ plane ──
  Mirrors G7-G16 features: X → -X

── G18 : Mirror across XZ plane ──
  Mirrors G7-G17 features: Y → -Y

── G19-G20 : Circle cut (S8) ──
  Circle centre: (0.0001, 57.0000)  Z=0.0
  Radius: 4.9999 mm
  Extrude cut: 2.0 mm  (−Z)

Watertight check  : True
STL volume        : 107905.89636130439 mm³
build123d volume  : 107937.99382490845 mm³

Exported files:
  STL  : Art1Top_Splitted_A_G_1_20.stl
  STEP : Art1Top_Splitted_A_G_1_20.step
============================================================

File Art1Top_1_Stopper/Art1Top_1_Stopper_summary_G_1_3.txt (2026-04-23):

=================================================================
  Art1Top_1_Stopper_build123d.py
  Started : 2026-04-23 11:51:35
=================================================================

-> [G1] Reading S1 (Fusion_Coordinates_S1.csv) ...
   → Circle centre  = (56.9998, 0.0000, 6.3000)
   → Circle radius  = 4.6002 mm
   → Sketch plane Z = 6.3000 mm
   → Chord line Y = -1.5000  [(61.349,-1.500) → (52.651,-1.500)]
   → Chord line Y = 1.5000  [(52.651,1.500) → (61.349,1.500)]
   → Region A (strip) : Y ∈ [-1.500, 1.500] ∩ circle
   → Region B (arc)   : Y > 1.500 ∩ circle
   → Region C (arc)   : Y < -1.500 ∩ circle
--- [G1] Complete ✓ ---

-> [G2] Building extrusions ...
   → Extruding full disc (A+B+C) by 1.2 mm in -Z ...
   ✓ Base disc volume = 79.7770 mm³
   → Extruding Region A (strip Y=[-1.5,1.5]) by 1.0 mm in +Z ...
   ✓ Strip (Region A) volume = 27.1038 mm³
   ✓ Combined solid volume   = 106.8807 mm³
--- [G2] Complete ✓ ---

=================================================================
  [G3]  PRE-EXPORT CHECKS & STL/STEP EXPORT
=================================================================

-> [G3] Watertight check ...
   Faces in solid : 7
   Free edges     : 0
   🟢 SUCCESS: Mesh is watertight!

   Final volume = 106.8807 mm³
   ✓ STL saved  : Art1Top_1_Stopper_G_1_3.stl  (51.1 KB)
   ✓ STEP saved : Art1Top_1_Stopper_G_1_3.step  (19.8 KB)

=================================================================
  BUILD COMPLETE — G1 through G3
  Finished : 2026-04-23 11:51:36  (0.3 s)
=================================================================

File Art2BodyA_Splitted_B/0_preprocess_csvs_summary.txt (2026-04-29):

============================================================
0_preprocess_csvs.py  Execution Log
Time: 2026-04-29 15:49:11
============================================================

Found 10 CSV file(s) in input folder.

SKIPPED  S1: already in csv_merged — not reprocessed.
SKIPPED  S2: already in csv_merged — not reprocessed.
SKIPPED  S3: already in csv_merged — not reprocessed.
SKIPPED  S4: already in csv_merged — not reprocessed.
SKIPPED  S5: already in csv_merged — not reprocessed.
SKIPPED  S6: already in csv_merged — not reprocessed.
SKIPPED  S7: already in csv_merged — not reprocessed.
SKIPPED  S8: already in csv_merged — not reprocessed.
SKIPPED  S9: already in csv_merged — not reprocessed.
WROTE    S10: Fusion_Coordinates_S10.csv → Fusion_Coordinates_S10.csv

============================================================
SUMMARY
============================================================
  Shapes skipped (already merged) : 9
  New shapes written              : 1
  Duplicate rows removed (total)  : 0
============================================================

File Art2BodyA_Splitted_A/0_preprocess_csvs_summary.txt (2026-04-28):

============================================================
0_preprocess_csvs.py  Execution Log
Time: 2026-04-27 12:27:49
============================================================

Found 12 CSV file(s) in input folder.

SKIPPED  S1: already in csv_merged — not reprocessed.
SKIPPED  S2: already in csv_merged — not reprocessed.
SKIPPED  S3: already in csv_merged — not reprocessed.
SKIPPED  S4: already in csv_merged — not reprocessed.
SKIPPED  S5: already in csv_merged — not reprocessed.
SKIPPED  S6: already in csv_merged — not reprocessed.
SKIPPED  S7: already in csv_merged — not reprocessed.
SKIPPED  S8: already in csv_merged — not reprocessed.
SKIPPED  S9: already in csv_merged — not reprocessed.
SKIPPED  S10: already in csv_merged — not reprocessed.
WROTE    S11: Fusion_Coordinates_S11.csv → Fusion_Coordinates_S11.csv
WROTE    S12: Fusion_Coordinates_S12.csv → Fusion_Coordinates_S12.csv

============================================================
SUMMARY
============================================================
  Shapes skipped (already merged) : 10
  New shapes written              : 2
  Duplicate rows removed (total)  : 0
============================================================

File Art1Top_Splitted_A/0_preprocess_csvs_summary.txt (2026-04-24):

============================================================
0_preprocess_csvs.py  Execution Log
Time: 2026-04-24 09:25:44
============================================================

Found 9 CSV file(s) in input folder.

SKIPPED  S1: already in csv_merged — not reprocessed.
SKIPPED  S2: already in csv_merged — not reprocessed.
SKIPPED  S3: already in csv_merged — not reprocessed.
SKIPPED  S4: already in csv_merged — not reprocessed.
SKIPPED  S5: already in csv_merged — not reprocessed.
SKIPPED  S6: already in csv_merged — not reprocessed.
SKIPPED  S7: already in csv_merged — not reprocessed.
SKIPPED  S8: already in csv_merged — not reprocessed.
WROTE    S9: Fusion_Coordinates_S9.csv → Fusion_Coordinates_S9.csv

============================================================
SUMMARY
============================================================
  Shapes skipped (already merged) : 8
  New shapes written              : 1
  Duplicate rows removed (total)  : 0
============================================================

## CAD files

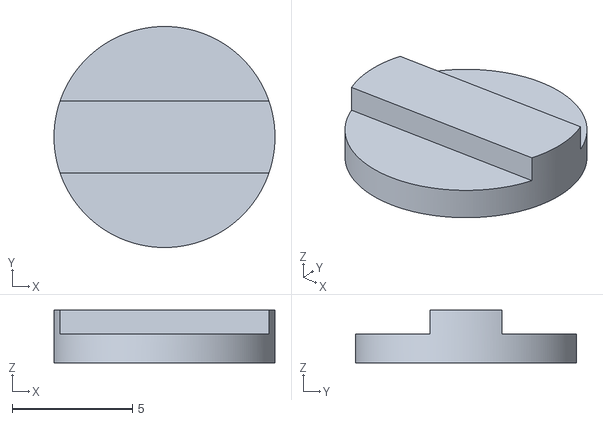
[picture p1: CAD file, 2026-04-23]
Art1Top_1_Stopper/Art1Top_1_Stopper_original.stl
9.20 x 9.20 x 2.20

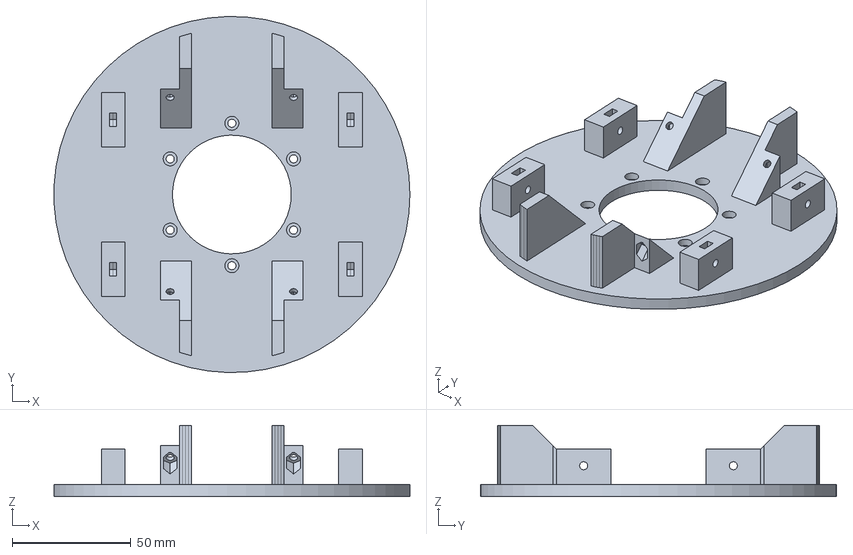
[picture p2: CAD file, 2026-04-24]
Art1Top_Splitted_A/Art1Top_Splitted_A_G_1_20.step
149.9 x 149.9 x 30.0 mm

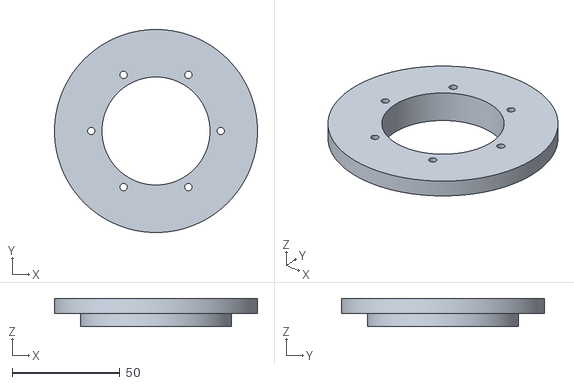
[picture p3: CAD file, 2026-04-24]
Art1Top_Splitted_B/Art1Top_Splitted_B_original.stl
94.0 x 94.0 x 13.0

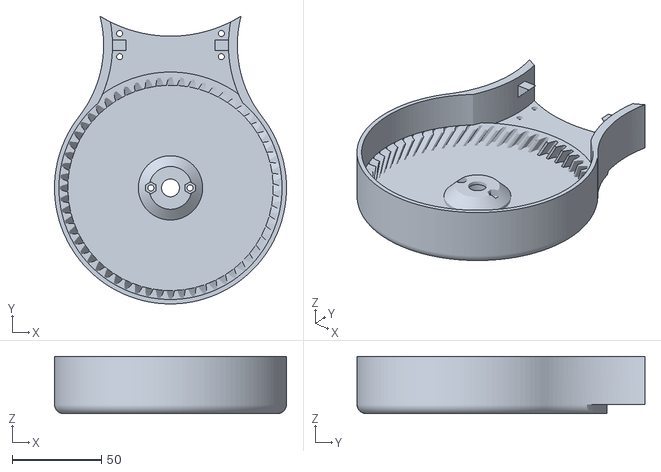
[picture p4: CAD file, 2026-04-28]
Art2BodyA_Splitted_A/Art2BodyA_Splitted_A_original.stl
130.0 x 161.3 x 32.0

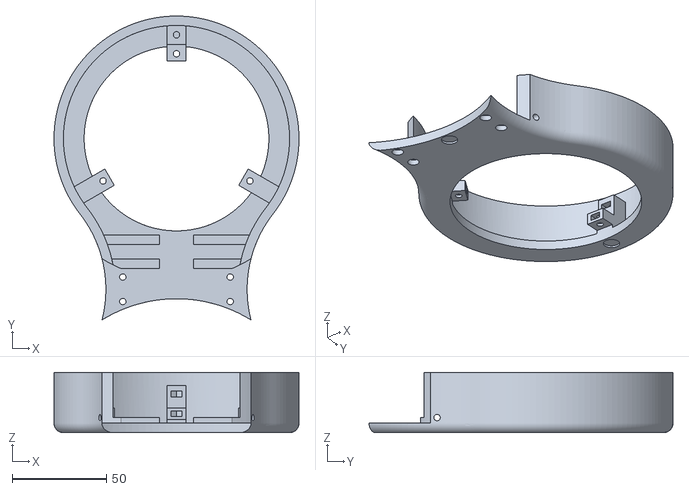
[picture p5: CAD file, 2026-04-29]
Art2BodyA_Splitted_B/Art2BodyA_Splitted_B_original.stl
130.0 x 161.3 x 32.0

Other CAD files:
Art1Top_1_Stopper/Art1Top_1_Stopper_G_1_3.step
Art1Top_Splitted_A/Art1Top_Splitted_A_original.stl
Art1Top_Splitted_B/Art1Top_Splitted_B_G_1_6.step
Art2BodyA_Splitted_B/Art2BodyA_Splitted_B_G_1_28.step
Art1Top_1_Stopper/Art1Top_1_Stopper_G_1_3.stl
Art1Top_Splitted_A/Art1Top_Splitted_A_G_1_20.stl
Art1Top_Splitted_B/Art1Top_Splitted_B_G_1_6.stl

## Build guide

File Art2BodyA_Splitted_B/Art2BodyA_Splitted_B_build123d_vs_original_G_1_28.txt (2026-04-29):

███████████████████████████████████████████████████████████
  STL COMPARISON: Build123d  vs  Fusion 360 Original
  Run time  : 2026-04-29  17:54:55
███████████████████████████████████████████████████████████
  Build123d : Art2BodyA_Splitted_B_G_1_28.stl
  Original  : Art2BodyA_Splitted_B_original.stl
  Report    : Art2BodyA_Splitted_B_build123d_vs_original_G_1_28.txt

  =========================================================
  Build123d STL

  =========================================================
  File           : Art2BodyA_Splitted_B_G_1_28.stl
  Triangles      : 1,105,134  (more = finer mesh = less approx error)
  Watertight     : True
  Volume         : 88495.3892 mm³
  Center of mass : (-0.000, 155.876, 11.332) mm
  X range        : -65.0000 → 65.0000 mm
  Y range        : 63.7320 → 225.0000 mm
  Z range        : 0.0000 → 32.0000 mm

  =========================================================
  Fusion 360 Original STL

  =========================================================
  File           : Art2BodyA_Splitted_B_original.stl
  Triangles      : 22,534  (more = finer mesh = less approx error)
  Watertight     : True
  Volume         : 88444.3441 mm³
  Center of mass : (-0.000, 155.852, 11.330) mm
  X range        : -64.9899 → 64.9899 mm
  Y range        : 63.7317 → 225.0000 mm
  Z range        : 0.0000 → 32.0000 mm

  =========================================================
  VOLUME COMPARISON

  =========================================================
  Metric                                   Value  Unit
  ---------------------------------------------------------
  Build123d volume                    88495.3892  mm³
  Fusion volume (reference)           88444.3441  mm³
  Absolute difference                   +51.0451  mm³  (build123d larger)
  % error vs original                     0.0577  %
  Rating                         🟢 EXCELLENT

  =========================================================
  SYMMETRIC DIFFERENCE  (spatial overlap quality)

  =========================================================
  Mesh A watertight : True
  Mesh B watertight : True

  Metric                                     Value  Unit
  ---------------------------------------------------------
  Volume A (Build123d)                  88495.3892  mm³
  Volume B (Fusion original)            88444.3441  mm³
  Intersection volume                   88344.6019  mm³
  Overlap coverage (inter/Fusion)          99.8872  %
  ---------------------------------------------------------
  Symmetric diff volume                   250.5295  mm³
  Sym diff % of Fusion volume               0.2833  %
  Rating                              🟢 EXCELLENT

  =========================================================
  BOUNDING BOX COMPARISON  (tolerance ±0.1 mm per axis)

  =========================================================
  Axis      Build123d       Fusion    Diff mm    % err  Status
  -----------------------------------------------------------------
  X min      -65.0000     -64.9899    -0.0101   0.008%  ✅ pass
  X max       65.0000      64.9899    +0.0101   0.008%  ✅ pass
  Y min       63.7320      63.7317    +0.0003   0.000%  ✅ pass
  Y max      225.0000     225.0000    +0.0000   0.000%  ✅ pass
  Z min        0.0000       0.0000    +0.0000   0.000%  ✅ pass
  Z max       32.0000      32.0000    +0.0000   0.000%  ✅ pass

  Overall bounding box : ✅ PASS

  █████████████████████████████████████████████████████████
  SUMMARY SCORECARD

  █████████████████████████████████████████████████████████
  Check                                    Score   Rating
  -----------------------------------------------------------------
  Volume % error                          0.058%   🟢 EXCELLENT
  Symmetric diff % error                  0.283%   🟢 EXCELLENT
  Overlap coverage                        99.89%   🟢 EXCELLENT
  Bounding box                              PASS   ✅

  █████████████████████████████████████████████████████████

  Report saved → /Users/avajones/Documents/ava_build123d/20260422_assign/Art2BodyA_Splitted_B/Art2BodyA_Splitted_B_build123d_vs_original_G_1_28.txt

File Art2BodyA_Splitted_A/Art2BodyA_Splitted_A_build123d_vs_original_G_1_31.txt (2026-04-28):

███████████████████████████████████████████████████████████
  STL COMPARISON: Build123d  vs  Fusion 360 Original
  Run time  : 2026-04-28  12:30:08
███████████████████████████████████████████████████████████
  Build123d : Art2BodyA_Splitted_A_G_1_31.stl
  Original  : Art2BodyA_Splitted_A_original.stl
  Report    : Art2BodyA_Splitted_A_build123d_vs_original_G_1_31.txt

  =========================================================
  Build123d STL

  =========================================================
  File           : Art2BodyA_Splitted_A_G_1_31.stl
  Triangles      : 272,464  (more = finer mesh = less approx error)
  Volume         : 102771.2917 mm³
  Center of mass : (0.000, 15.961, 8.794) mm
  X range        : -65.0001 → 65.0001 mm
  Y range        : -65.0002 → 96.2680 mm
  Z range        : 0.0000 → 32.0000 mm

  =========================================================
  Fusion 360 Original STL

  =========================================================
  File           : Art2BodyA_Splitted_A_original.stl
  Triangles      : 19,776  (more = finer mesh = less approx error)
  Volume         : 102976.0625 mm³
  Center of mass : (-0.002, 15.979, 8.787) mm
  X range        : -64.9899 → 64.9899 mm
  Y range        : -65.0000 → 96.2683 mm
  Z range        : 0.0000 → 32.0000 mm

  =========================================================
  VOLUME COMPARISON

  =========================================================
  Metric                                   Value  Unit
  ---------------------------------------------------------
  Build123d volume                   102771.2917  mm³
  Fusion volume (reference)          102976.0625  mm³
  Absolute difference                  -204.7708  mm³  (build123d smaller)
  % error vs original                     0.1989  %
  Rating                         🟢 EXCELLENT

  =========================================================
  SYMMETRIC DIFFERENCE  (spatial overlap quality)

  =========================================================
  Mesh A watertight : True
  Mesh B watertight : True

  Metric                                     Value  Unit
  ---------------------------------------------------------
  Volume A (Build123d)                 102778.9019  mm³
  Volume B (Fusion original)           102979.8516  mm³
  Intersection volume                  102581.1690  mm³
  Overlap coverage (inter/Fusion)          99.6129  %
  ---------------------------------------------------------
  Symmetric diff volume                   596.4154  mm³
  Sym diff % of Fusion volume               0.5792  %
  Rating                              🟢 EXCELLENT

  =========================================================
  BOUNDING BOX COMPARISON  (tolerance ±0.1 mm per axis)

  =========================================================
  Axis      Build123d       Fusion    Diff mm    % err  Status
  -----------------------------------------------------------------
  X min      -65.0001     -64.9899    -0.0102   0.008%  ✅ pass
  X max       65.0001      64.9899    +0.0102   0.008%  ✅ pass
  Y min      -65.0002     -65.0000    -0.0002   0.000%  ✅ pass
  Y max       96.2680      96.2683    -0.0003   0.000%  ✅ pass
  Z min        0.0000       0.0000    +0.0000   0.000%  ✅ pass
  Z max       32.0000      32.0000    +0.0000   0.000%  ✅ pass

  Overall bounding box : ✅ PASS

  █████████████████████████████████████████████████████████
  SUMMARY SCORECARD

  █████████████████████████████████████████████████████████
  Check                                    Score   Rating
  -----------------------------------------------------------------
  Volume % error                          0.199%   🟢 EXCELLENT
  Symmetric diff % error                  0.579%   🟢 EXCELLENT
  Overlap coverage                        99.61%   🟢 EXCELLENT
  Bounding box                              PASS   ✅

  █████████████████████████████████████████████████████████

  Report saved → /Users/avajones/Documents/ava_build123d/20260422_assign/Art2BodyA_Splitted_A/Art2BodyA_Splitted_A_build123d_vs_original_G_1_31.txt

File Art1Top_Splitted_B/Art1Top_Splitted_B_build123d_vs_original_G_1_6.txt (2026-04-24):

███████████████████████████████████████████████████████████
  STL COMPARISON: Build123d  vs  Fusion 360 Original
  Run time  : 2026-04-24  10:49:02
███████████████████████████████████████████████████████████
  Build123d : Art1Top_Splitted_B_G_1_6.stl
  Original  : Art1Top_Splitted_B_original.stl
  Report    : Art1Top_Splitted_B_build123d_vs_original_G_1_6.txt

  =========================================================
  Build123d STL

  =========================================================
  File           : Art1Top_Splitted_B_G_1_6.stl
  Triangles      : 4,560  (more = finer mesh = less approx error)
  Volume         : 45416.2917 mm³
  Center of mass : (0.000, -0.000, 7.929) mm
  X range        : -46.9999 → 46.9999 mm
  Y range        : -46.9853 → 46.9853 mm
  Z range        : 0.0000 → 13.0000 mm

  =========================================================
  Fusion 360 Original STL

  =========================================================
  File           : Art1Top_Splitted_B_original.stl
  Triangles      : 8,268  (more = finer mesh = less approx error)
  Volume         : 45429.8073 mm³
  Center of mass : (0.000, 0.000, 7.929) mm
  X range        : -46.9989 → 46.9989 mm
  Y range        : -46.9956 → 47.0000 mm
  Z range        : -0.0000 → 13.0000 mm

  =========================================================
  VOLUME COMPARISON

  =========================================================
  Metric                                   Value  Unit
  ---------------------------------------------------------
  Build123d volume                    45416.2917  mm³
  Fusion volume (reference)           45429.8073  mm³
  Absolute difference                   -13.5156  mm³  (build123d smaller)
  % error vs original                     0.0298  %
  Rating                         🟢 EXCELLENT

  =========================================================
  SYMMETRIC DIFFERENCE  (spatial overlap quality)

  =========================================================
  Mesh A watertight : True
  Mesh B watertight : True

  Metric                                     Value  Unit
  ---------------------------------------------------------
  Volume A (Build123d)                  45416.2464  mm³
  Volume B (Fusion original)            45429.8346  mm³
  Intersection volume                   45408.1700  mm³
  Overlap coverage (inter/Fusion)          99.9523  %
  ---------------------------------------------------------
  Symmetric diff volume                    29.7409  mm³
  Sym diff % of Fusion volume               0.0655  %
  Rating                              🟢 EXCELLENT

  =========================================================
  BOUNDING BOX COMPARISON  (tolerance ±0.1 mm per axis)

  =========================================================
  Axis      Build123d       Fusion    Diff mm    % err  Status
  -----------------------------------------------------------------
  X min      -46.9999     -46.9989    -0.0010   0.001%  ✅ pass
  X max       46.9999      46.9989    +0.0010   0.001%  ✅ pass
  Y min      -46.9853     -46.9956    +0.0103   0.011%  ✅ pass
  Y max       46.9853      47.0000    -0.0147   0.016%  ✅ pass
  Z min        0.0000      -0.0000    +0.0000   0.000%  ✅ pass
  Z max       13.0000      13.0000    +0.0000   0.000%  ✅ pass

  Overall bounding box : ✅ PASS

  █████████████████████████████████████████████████████████
  SUMMARY SCORECARD

  █████████████████████████████████████████████████████████
  Check                                    Score   Rating
  -----------------------------------------------------------------
  Volume % error                          0.030%   🟢 EXCELLENT
  Symmetric diff % error                  0.065%   🟢 EXCELLENT
  Overlap coverage                        99.95%   🟢 EXCELLENT
  Bounding box                              PASS   ✅

  █████████████████████████████████████████████████████████

  Report saved → /Users/avajones/Documents/ava_build123d/20260422_assign/Art1Top_Splitted_B/Art1Top_Splitted_B_build123d_vs_original_G_1_6.txt

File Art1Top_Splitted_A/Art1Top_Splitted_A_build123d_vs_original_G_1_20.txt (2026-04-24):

███████████████████████████████████████████████████████████
  STL COMPARISON: Build123d  vs  Fusion 360 Original
  Run time  : 2026-04-24  09:36:24
███████████████████████████████████████████████████████████
  Build123d : Art1Top_Splitted_A_G_1_20.stl
  Original  : Art1Top_Splitted_A_original.stl
  Report    : Art1Top_Splitted_A_build123d_vs_original_G_1_20.txt

  =========================================================
  Build123d STL

  =========================================================
  File           : Art1Top_Splitted_A_G_1_20.stl
  Triangles      : 14,608  (more = finer mesh = less approx error)
  Volume         : 107906.0625 mm³
  Center of mass : (0.000, -0.083, 5.563) mm
  X range        : -75.0001 → 75.0001 mm
  Y range        : -74.9767 → 74.9767 mm
  Z range        : 0.0000 → 30.0000 mm

  =========================================================
  Fusion 360 Original STL

  =========================================================
  File           : Art1Top_Splitted_A_original.stl
  Triangles      : 25,364  (more = finer mesh = less approx error)
  Volume         : 107931.2917 mm³
  Center of mass : (-0.000, -0.083, 5.562) mm
  X range        : -74.9950 → 75.0000 mm
  Y range        : -74.9988 → 74.9988 mm
  Z range        : 0.0000 → 30.0000 mm

  =========================================================
  VOLUME COMPARISON

  =========================================================
  Metric                                   Value  Unit
  ---------------------------------------------------------
  Build123d volume                   107906.0625  mm³
  Fusion volume (reference)          107931.2917  mm³
  Absolute difference                   -25.2292  mm³  (build123d smaller)
  % error vs original                     0.0234  %
  Rating                         🟢 EXCELLENT

  =========================================================
  SYMMETRIC DIFFERENCE  (spatial overlap quality)

  =========================================================
  Mesh A watertight : True
  Mesh B watertight : True

  Metric                                     Value  Unit
  ---------------------------------------------------------
  Volume A (Build123d)                 107905.8964  mm³
  Volume B (Fusion original)           107931.5416  mm³
  Intersection volume                  107902.2784  mm³
  Overlap coverage (inter/Fusion)          99.9729  %
  ---------------------------------------------------------
  Symmetric diff volume                    32.8812  mm³
  Sym diff % of Fusion volume               0.0305  %
  Rating                              🟢 EXCELLENT

  =========================================================
  BOUNDING BOX COMPARISON  (tolerance ±0.1 mm per axis)

  =========================================================
  Axis      Build123d       Fusion    Diff mm    % err  Status
  -----------------------------------------------------------------
  X min      -75.0001     -74.9950    -0.0050   0.003%  ✅ pass
  X max       75.0001      75.0000    +0.0001   0.000%  ✅ pass
  Y min      -74.9767     -74.9988    +0.0220   0.015%  ✅ pass
  Y max       74.9767      74.9988    -0.0220   0.015%  ✅ pass
  Z min        0.0000       0.0000    +0.0000   0.000%  ✅ pass
  Z max       30.0000      30.0000    +0.0000   0.000%  ✅ pass

  Overall bounding box : ✅ PASS

  █████████████████████████████████████████████████████████
  SUMMARY SCORECARD

  █████████████████████████████████████████████████████████
  Check                                    Score   Rating
  -----------------------------------------------------------------
  Volume % error                          0.023%   🟢 EXCELLENT
  Symmetric diff % error                  0.030%   🟢 EXCELLENT
  Overlap coverage                        99.97%   🟢 EXCELLENT
  Bounding box                              PASS   ✅

  █████████████████████████████████████████████████████████

  Report saved → /Users/avajones/Documents/ava_build123d/20260422_assign/Art1Top_Splitted_A/Art1Top_Splitted_A_build123d_vs_original_G_1_20.txt

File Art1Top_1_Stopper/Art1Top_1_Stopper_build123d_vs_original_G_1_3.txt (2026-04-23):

███████████████████████████████████████████████████████████
  STL COMPARISON: Build123d  vs  Fusion 360 Original
  Run time  : 2026-04-23  11:54:10
███████████████████████████████████████████████████████████
  Build123d : Art1Top_1_Stopper_G_1_3.stl
  Original  : Art1Top_1_Stopper_original.stl
  Report    : Art1Top_1_Stopper_build123d_vs_original_G_1_3.txt

  =========================================================
  Build123d STL

  =========================================================
  File           : Art1Top_1_Stopper_G_1_3.stl
  Triangles      : 1,044  (more = finer mesh = less approx error)
  Volume         : 106.8725 mm³
  Center of mass : (57.000, 0.000, 5.979) mm
  X range        : 52.3997 → 61.6000 mm
  Y range        : -4.6002 → 4.6002 mm
  Z range        : 5.1000 → 7.3000 mm

  =========================================================
  Fusion 360 Original STL

  =========================================================
  File           : Art1Top_1_Stopper_original.stl
  Triangles      : 928  (more = finer mesh = less approx error)
  Volume         : 106.8644 mm³
  Center of mass : (57.000, 0.000, 5.979) mm
  X range        : 52.4004 → 61.6000 mm
  Y range        : -4.5999 → 4.5999 mm
  Z range        : 5.1000 → 7.3000 mm

  =========================================================
  VOLUME COMPARISON

  =========================================================
  Metric                                   Value  Unit
  ---------------------------------------------------------
  Build123d volume                      106.8725  mm³
  Fusion volume (reference)             106.8644  mm³
  Absolute difference                    +0.0082  mm³  (build123d larger)
  % error vs original                     0.0076  %
  Rating                         🟢 EXCELLENT

  =========================================================
  SYMMETRIC DIFFERENCE  (spatial overlap quality)

  =========================================================
  Mesh A watertight : True
  Mesh B watertight : True

  Metric                                     Value  Unit
  ---------------------------------------------------------
  Volume A (Build123d)                    106.8725  mm³
  Volume B (Fusion original)              106.8644  mm³
  Intersection volume                     106.8639  mm³
  Overlap coverage (inter/Fusion)          99.9995  %
  ---------------------------------------------------------
  Symmetric diff volume                     0.0092  mm³
  Sym diff % of Fusion volume               0.0086  %
  Rating                              🟢 EXCELLENT

  =========================================================
  BOUNDING BOX COMPARISON  (tolerance ±0.1 mm per axis)

  =========================================================
  Axis      Build123d       Fusion    Diff mm    % err  Status
  -----------------------------------------------------------------
  X min       52.3997      52.4004    -0.0007   0.008%  ✅ pass
  X max       61.6000      61.6000    +0.0000   0.000%  ✅ pass
  Y min       -4.6002      -4.5999    -0.0003   0.003%  ✅ pass
  Y max        4.6002       4.5999    +0.0003   0.003%  ✅ pass
  Z min        5.1000       5.1000    +0.0000   0.000%  ✅ pass
  Z max        7.3000       7.3000    +0.0000   0.000%  ✅ pass

  Overall bounding box : ✅ PASS

  █████████████████████████████████████████████████████████
  SUMMARY SCORECARD

  █████████████████████████████████████████████████████████
  Check                                    Score   Rating
  -----------------------------------------------------------------
  Volume % error                          0.008%   🟢 EXCELLENT
  Symmetric diff % error                  0.009%   🟢 EXCELLENT
  Overlap coverage                       100.00%   🟢 EXCELLENT
  Bounding box                              PASS   ✅

  █████████████████████████████████████████████████████████

  Report saved → /Users/avajones/Documents/ava_build123d/20260422_assign/Art1Top_1_Stopper/Art1Top_1_Stopper_build123d_vs_original_G_1_3.txt

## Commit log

2026-04-23 part 1 done
    [Art1Top_1_Stopper_G_1_3.step, Art1Top_1_Stopper_G_1_3.stl, Art1Top_1_Stopper_original.stl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]
2026-04-23 path modified
    [Art1Top_1_Stopper_G_1_3.step, Art1Top_1_Stopper_G_1_3.stl, Art1Top_1_Stopper_original.stl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]
2026-04-24 part 2 uploaded
    [Art1Top_Splitted_A_G_1_20.step, Art1Top_Splitted_A_G_1_20.stl, Art1Top_Splitted_A_original.stl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]
2026-04-24 part 3 uploaded
    [Art1Top_Splitted_B_G_1_6.step, Art1Top_Splitted_B_G_1_6.stl, Art1Top_Splitted_B_original.stl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]
